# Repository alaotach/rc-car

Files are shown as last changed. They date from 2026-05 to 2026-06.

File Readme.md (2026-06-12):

# Quixie - RC Delivery Car

Quixie is a small autonomous RC delivery car. The custom PCB handles motor control and sensor expansion; the firmware manages navigation, telemetry, and the locking cargo bay.

> Built by **AlAoTach** for [Fallout](https://fallout.hackclub.com/)

Blue and Pink Modern Film Poster

---

## Why I Built This

I wanted to steal chips from my nephew.

---

## Key Features

- **Servo locked cargo bay** - lid opens and closes automatically via servo motor
- **Live camera feed** - ESP32-CAM streamed to the web dashboard
- **GPS navigation** - Neo-8M for real-time position tracking
- **Obstacle avoidance** - 3× ultrasonic sensors
- **OLED display** - SSD1306 1.3" on-device status screen
---

## Tech Specs

| Component | Part |
|---|---|
| MCU | ESP32 Mini (ESP32-S3) |
| Motors | Dual DC Geared, 12V |
| Driver | BTN7960B (43A) |
| GPS | Neo-6M |
| IMU | BMI270 |
| Sensors | Ultrasonic ×3 |
| Camera | ESP32-CAM |
| Display | SSD1306 OLED (1.11") |
| Battery | 3S Li-ion (11.1V) |
| Comms | WiFi — Web + WebSocket |

---

## System Overview

image-Photoroom

---

## What's in This Repo

```
quixie/
├── pcb/                          # KiCad project
│   ├── rc-car.kicad_pcb          # PCB layout
│   ├── rc-car.kicad_sch          # Schematic
│   ├── rc-car.kicad_pro          # Project file
│   ├── rc-car-BOM.csv            # Bill of materials
│   └── fabrication/              # Gerbers + drill files
├── firmware/
│   └── rc-car/
│       ├── include/              # Header files + Config.h
│       └── src/                  # Source files
├── fabrication/
│   └── 3d/
│       ├── rc-car-case.f3d       # Fusion 360 CAD source
│       ├── rc-car-case.stl       # 3D printable case
│       └── pcb-model.stl         # 3D PCB model
└── docs/assets/                  # Images and media
```

---

## PCB

Front and back of the custom PCB:

Screenshot 2026-06-10 111952-Photoroom

Screenshot 2026-06-10 112009-Photoroom

---

## 3D Case

The case is 3D printable in PLA.

rc-car_2026-Jun-09_08-27-36PM-000_CustomizedView2119663068
rc-car_2026-Jun-09_08-28-37PM-000_CustomizedView30783760963
450aec4a-f353-46d9-9899-f3d45b1544f4

**Open cargo bay**

open-lid

---

## Schematic

### Main schema
schema-quixie-1

### Motor schema
schema-quixie-2

### Ultrasonic and TOF
schema-quixie-3

### Servo lock
schema-quixie-4

### Voltage divider
schema-quixie-5

### Battery and charging
schema-quixie-6

---

## Build Guide

### Step 1 - Export Gerbers

Open `pcb/rc-car.kicad_pcb` in KiCad. Generate Gerbers and drill files into `pcb/fabrication/`. Zip all outputs.

### Step 2 - Order the PCB

Upload your Gerber zip to [JLCPCB](https://jlcpcb.com) or your preferred fab.

### Step 3 - Solder & Populate

Solder the required components ( hope you have gotten SMD from jlcpcb )

### Step 4 - Flash Firmware

```bash
cd firmware/rc-car
pio run --target upload
```

Requires [PlatformIO](https://platformio.org/). Main config is in `firmware/rc-car/include/Config.h`.

### Step 5 - 3D Print the Case

- Material: PLA (PETG also works)
- File: `fabrication/3d/rc-car-case.stl`
- No supports needed for most orientations

### Step 6 - Final Assembly

Mount the PCB in the case, wire motors and power, connect sensors. The servo for the lid attaches at the rear hinge point.

---

## Modifying the Firmware

All config parameters live in:

```
firmware/rc-car/include/Config.h
```

Features are split into modules under `firmware/rc-car/src/`.

---

## License

Open source. Do what you want, just don't use it to steal chips from *my* nephew *cough cough*.

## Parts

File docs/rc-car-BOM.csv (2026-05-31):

Reference | Qty | Value | Footprint | Price | Total Price | URL
C1,C4,C10,C12,C13,C20,C27,C34,C39,C44 | 10 | 100nF | Capacitor_SMD:C_0603_1608Metric | 0.07 | 0.7
C2,C3,C9,C11,C19,C23,C24,C26,C33,C38,C43 | 11 | 10uF | Capacitor_SMD:C_0603_1608Metric | 0.07 | 0.77
C5,C6,C7 | 3 | 1uF | Capacitor_SMD:C_0603_1608Metric | 0.07 | 0.21
C8 | 1 | 22pF | Capacitor_SMD:C_0603_1608Metric | 0.07 | 0.07
C14,C15 | 2 | 220uF | Capacitor_SMD:C_0603_1608Metric | 0.07 | 0.14
C25,C32,C37,C42 | 4 | 470uF | Capacitor_SMD:C_0603_1608Metric | 0.07 | 0.28
D1,D2 | 2 | LED | LED_SMD:LED_0201_0603Metric | 0.07 | 0.14
J1 | 1 | UART | Connector_PinHeader_2.54mm:PinHeader_1x03_P2.54mm_Vertical | 3.1 | 3.1 | https://www.electropi.in/usb-to-serial-adapter-module-usb-to-ttl-rs232-arduino-cable-with-cts-rts
J2,J4,J5 | 3 | Ultrasonic | Connector_PinHeader_2.54mm:PinHeader_1x04_P2.54mm_Vertical | 0.72 | 2.16 | https://robu.in/product/hc-sr04-ultrasonic-range-finder/
J3 | 1 | OLED | Connector_PinHeader_2.54mm:PinHeader_1x04_P2.54mm_Vertical | 4.05 | 4.05 | https://robu.in/product/1-3-oled-display-v2/
J6,J7 | 2 | Servo | Connector_PinHeader_2.54mm:PinHeader_1x03_P2.54mm_Vertical | 2.4 | 4.8 | https://www.amazon.in/DHRUVPRO-Micro-Servo-Motor-Helicopter/dp/B09ZT8X5SM
J8 | 1 | BMS | Connector_PinHeader_2.54mm:PinHeader_1x06_P2.54mm_Vertical | 3.7 | 3.7 | https://www.amazon.in/LAND-INDIA-40A-BMS-Over-Discharge/dp/B0D3SMXRV9
J9,J14, J10,J15 | 4 | motor | Connector_PinHeader_2.54mm:PinHeader_1x02_P2.54mm_Vertical | 2.68 | 10.72 | https://robu.in/product/200rpm-12v-low-noise-dc-motor-with-metal-gears-grade-a/
 |  |  |  |  | 0
J11 | 1 | Battery | Connector_JST:JST_XH_B4B-XH-AM_1x04_P2.50mm_Vertical | 12.9 | 12.9 | https://www.electropi.in/11.1v-2200mah-lipo-battery-india
J12 | 1 | XT30PW-M | XT30PW-M:AMASS_XT30PW-M | 0.5 | 0.5 | https://robu.in/product/amass-xt30pw30-female-connector-xt30pw-f30-g-y/
J13 | 1 | USB_C_Receptacle_USB2.0_14P | Connector_USB:USB_C_Receptacle_HRO_TYPE-C-31-M-12 |  | 1
L1 | 1 | 10uH | Inductor_SMD:L_0201_0603Metric | 0.07 | 0.07
Q1,Q2 | 2 | Q_NMOS_GDS | Package_TO_SOT_SMD:TO-263-2 | 0.5 | 1
R1,R4,R6 | 3 | 1kOhm | Resistor_SMD:R_0603_1608Metric_Pad0.98x0.95mm_HandSolder | 0.07 | 0.21
R2,R3,R5 | 3 | 2kOhm | Resistor_SMD:R_0603_1608Metric_Pad0.98x0.95mm_HandSolder | 0.07 | 0.21
R7,R9 | 2 | 5.1kOhm | Resistor_SMD:R_0603_1608Metric_Pad0.98x0.95mm_HandSolder | 0.07 | 0.14
R10,R11,R12,R13,R14,R15 | 6 | 10kOhm | Resistor_SMD:R_0603_1608Metric | 0.07 | 0.42
R16 | 1 | 5.23kOhm | Resistor_SMD:R_0603_1608Metric | 0.07 | 0.07
R17 | 1 | 30.1kOhm | Resistor_SMD:R_0603_1608Metric | 0.07 | 0.07
R18 | 1 | 20mOhm | Resistor_SMD:R_0603_1608Metric | 0.07 | 0.07
R19,R21 | 2 | 499kOhm | Resistor_SMD:R_0603_1608Metric | 0.07 | 0.14
R20 | 1 | 100kOhm | Resistor_SMD:R_0603_1608Metric | 0.07 | 0.07
R22 | 1 | 36kOhm | Resistor_SMD:R_0603_1608Metric | 0.07 | 0.07
TH1 | 1 | Thermistor | Resistor_SMD:R_0805_2012Metric | 0.07 | 0.07
U1 | 1 | ESP32-S3-MINI-1 | RF_Module:ESP32-S2-MINI-1 | 18.7 | 18.7 | https://www.amazon.in/dp/B0G8ZWDDM6
U2 | 1 | AP2112K-3.3 | Package_TO_SOT_SMD:SOT-23-5 | 0.25 | 0.25 | https://robu.in/product/ap2112k-1-8trg1-diodes-incorporated-65db1khz-600ma-fixed-1-8v-positive-6v-sot-25-voltage-regulators-linear-low-drop-out-ldo-regulators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
U3 | 1 | NEO-M8M | RF_GPS:ublox_NEO | 10.2 | 10.2 | https://robu.in/product/apm2-5-ublox-neo-m8n-gps-module-gygpsv1-8m-3-5v-gygpsv5-neo-pixhawk-apm-ceramic-active-antenna/
U4 | 1 | IP2721 | Package_SO:TSSOP-16_4.4x5mm_P0.65mm | 1 | 1 | https://www.jakelectronics.com/productdetail/injoinic-ip2721-21164566
U5 | 1 | BQ24650 | Package_DFN_QFN:Texas_RVA_VQFN-16-1EP_3.5x3.5mm_P0.5mm_EP2.14x2.14mm_ThermalVias | 6 | 6 | https://www.lioncircuits.com/parts/BQ24650RVAR
U6 | 1 | LM2596S-5 | Package_TO_SOT_SMD:TO-263-5_TabPin3 | 0.7 | 0.7 | https://robu.in/product/lm2596s-5-0-xblw-step-down-type-fixed-5v-to-263-5l-dc-dc-converters-rohs/
U7 | 1 | TMF8828 | Sensor_Distance:AMS_OLGA12 | 1.32 | 1.32 | https://robu.in/product/vl53l0x-tof-based-lidar-laser-distance-sensor/
U8 | 1 | BMI270 | BMI270:XDCR_BMI270 | 3.4 | 3.4 | https://www.utmel.com/productdetail/boschsensortec-bmi270-6195042
U9,U10,U11,U12 | 4 | BTN7960B_LA | BTN7960B:IC_BTN7960B | 1.55 | 6.2 | https://www.ktron.in/product/bts7960-motor-driver-ic-43a-h-bridge-high/
 |  |  |  |  | 95.62

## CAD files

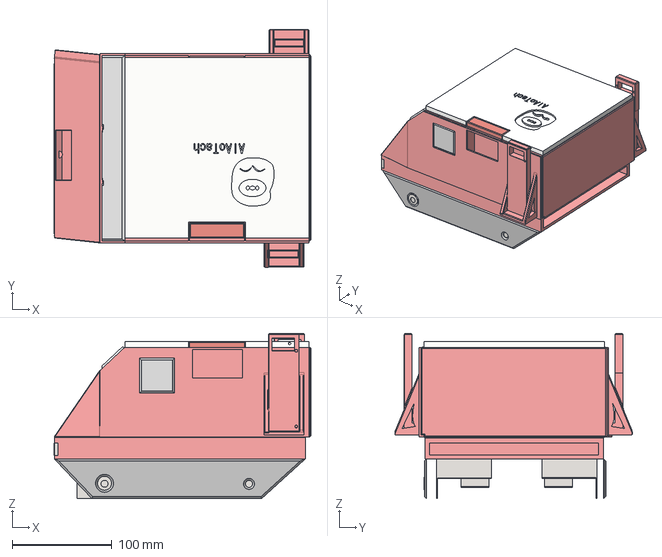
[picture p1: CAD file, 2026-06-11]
fabrication/3d/rc-car.step
258.1 x 238.7 x 166.0 mm

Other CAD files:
fabrication/3d/rc-car-case.stl
fabrication/3d/pcb-model.stl
fabrication/3d/rc-car-case.f3d

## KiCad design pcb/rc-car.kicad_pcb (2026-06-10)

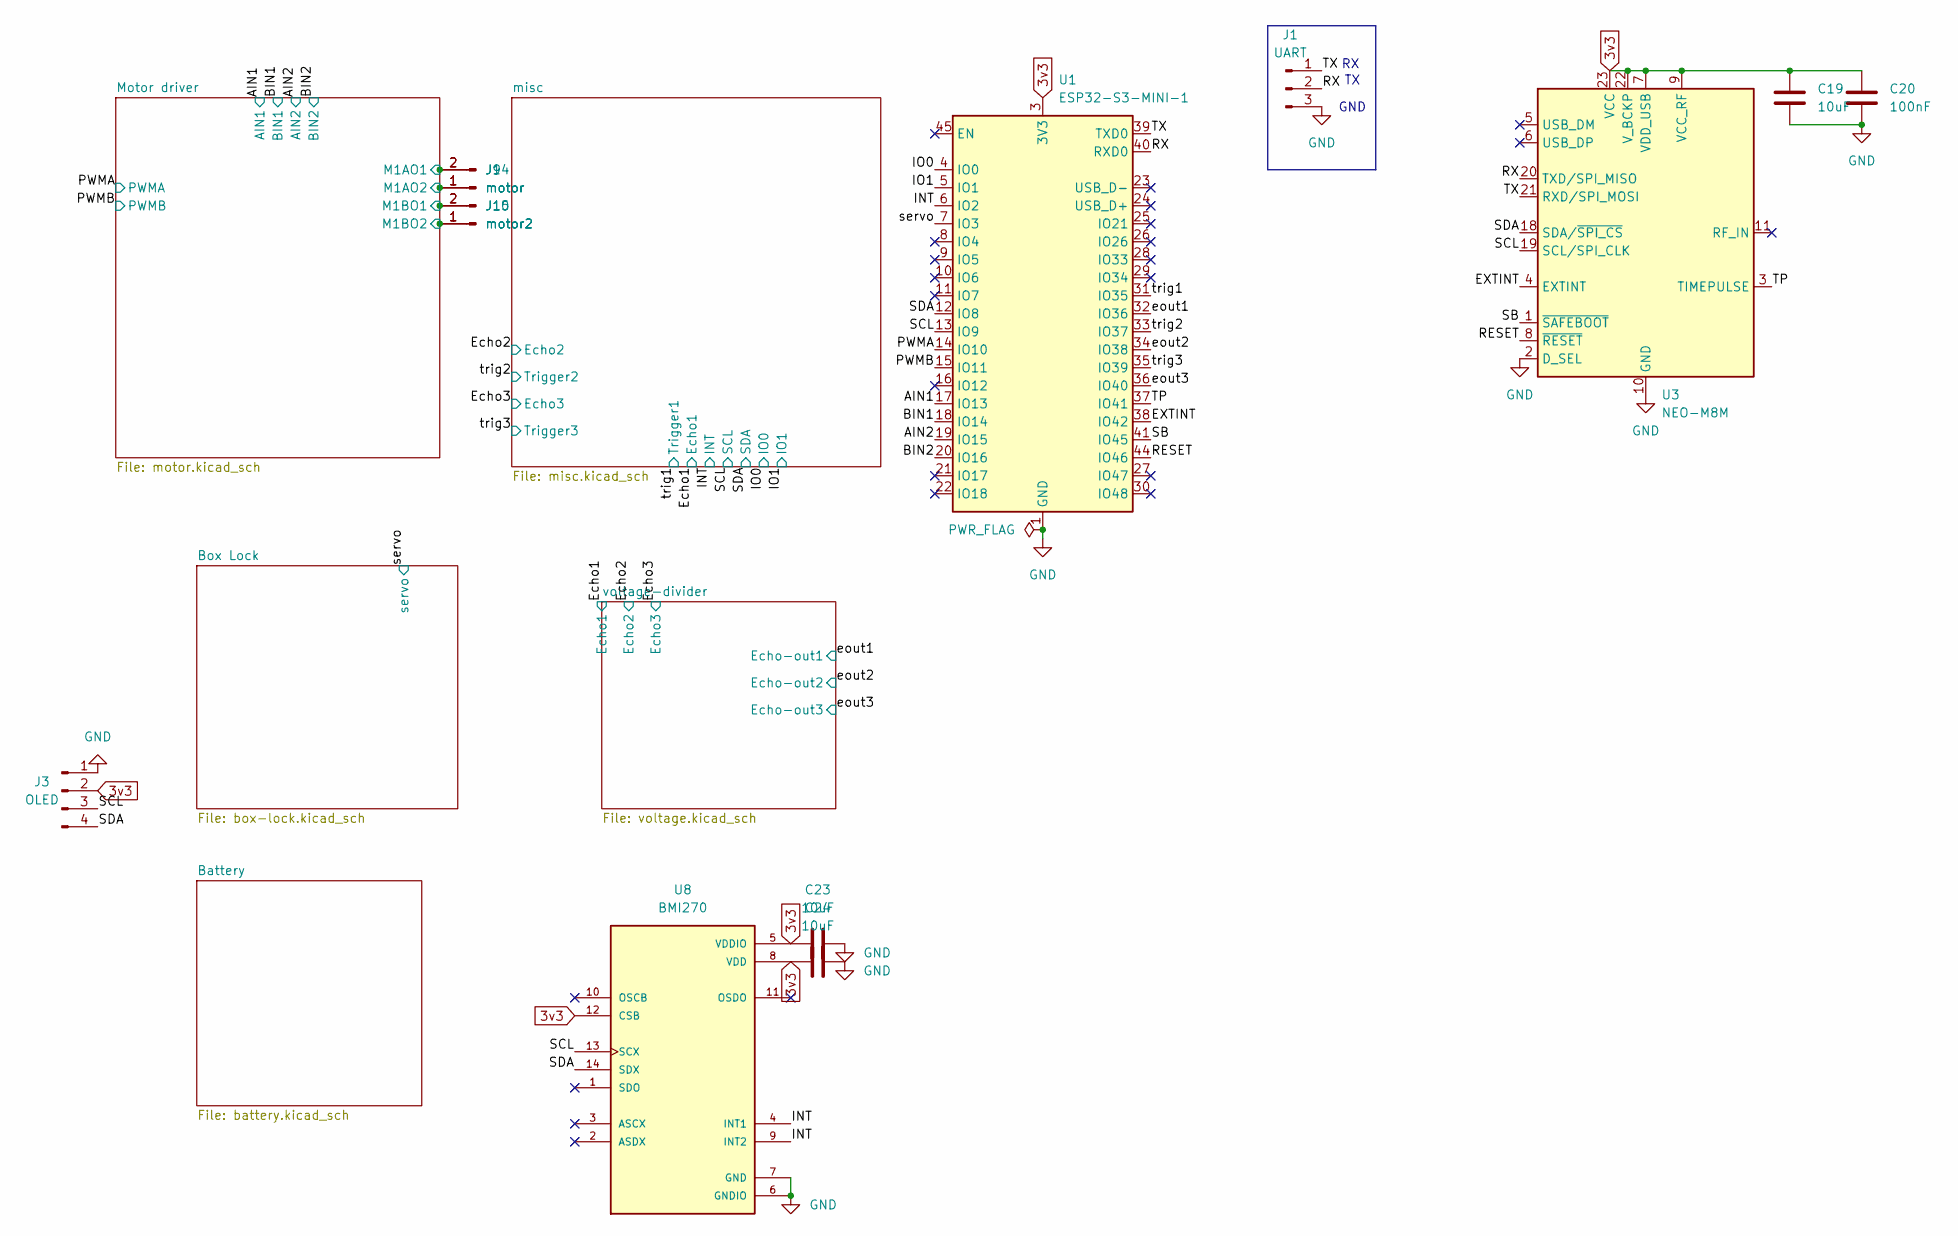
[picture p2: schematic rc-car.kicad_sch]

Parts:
C19, C23, C24: 10uF; C_0603_1608Metric
C20: 100nF; C_0603_1608Metric
J1: UART; PinHeader_1x03_P2.54mm_Vertical
J3: OLED; PinHeader_1x04_P2.54mm_Vertical
J9, J14: motor; PinHeader_1x02_P2.54mm_Vertical
J10, J15: motor2; PinHeader_1x02_P2.54mm_Vertical
U1: ESP32-S3-MINI-1; ESP32-S2-MINI-1
U3: NEO-M8M; ublox_NEO
U8: BMI270; XDCR_BMI270

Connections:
3v3: C19.1, C20.1, C23.1, C24.1, J3.2, U1.3 (3V3), U3.7 (VDD_USB), U3.9 (VCC_RF), U3.22 (V_BCKP), U3.23 (VCC), U8.5 (VDDIO), U8.8 (VDD), U8.12 (CSB); also elsewhere on the board
/AIN1: U1.17 (IO13); also elsewhere on the board
/AIN2: U1.19 (IO15); also elsewhere on the board
/BIN1: U1.18 (IO14); also elsewhere on the board
/BIN2: U1.20 (IO16); also elsewhere on the board
/EXTINT: U1.38 (IO42), U3.4 (EXTINT)
/INT: U1.6 (IO2), U8.4 (INT1), U8.9 (INT2); also elsewhere on the board
/IO0: U1.4 (IO0); also elsewhere on the board
/IO1: U1.5 (IO1); also elsewhere on the board
/Motor driver/M1AO1: J9.2, J14.2; also elsewhere on the board
/Motor driver/M1AO2: J9.1, J14.1; also elsewhere on the board
/Motor driver/M1BO1: J10.2, J15.2; also elsewhere on the board
/Motor driver/M1BO2: J10.1, J15.1; also elsewhere on the board
/PWMA: U1.14 (IO10); also elsewhere on the board
/PWMB: U1.15 (IO11); also elsewhere on the board
/RESET: U1.44 (IO46), U3.8 (~RESET)
/RX: J1.2, U1.40 (RXD0), U3.20 (TXD/SPI_MISO)
/SB: U1.41 (IO45), U3.1 (~SAFEBOOT)
/SCL: J3.3, U1.13 (IO9), U3.19 (SCL/SPI_CLK), U8.13 (SCX); also elsewhere on the board
/SDA: J3.4, U1.12 (IO8), U3.18 (SDA/~SPI_CS), U8.14 (SDX); also elsewhere on the board
/TP: U1.37 (IO41), U3.3 (TIMEPULSE)
/TX: J1.1, U1.39 (TXD0), U3.21 (RXD/SPI_MOSI)
/eout1: U1.32 (IO36); also elsewhere on the board
/eout2: U1.34 (IO38); also elsewhere on the board
/eout3: U1.36 (IO40); also elsewhere on the board
/servo: U1.7 (IO3); also elsewhere on the board
/trig1: U1.31 (IO35); also elsewhere on the board
/trig2: U1.33 (IO37); also elsewhere on the board
/trig3: U1.35 (IO39); also elsewhere on the board
GND: C19.2, C20.2, C23.2, C24.2, J1.3, J3.1, U1.1 (GND), U1.2 (GND), U1.42 (GND), U1.43 (GND), U1.46 (GND), U1.47 (GND), U1.48 (GND), U1.49 (GND), U1.50 (GND), U1.51 (GND), U1.52 (GND), U1.53 (GND), U1.54 (GND), U1.55 (GND), U1.56 (GND), U1.57 (GND), U1.58 (GND), U1.59 (GND), U1.60 (GND), U1.61 (GND), U1.62 (GND), U1.63 (GND), U1.64 (GND), U1.65 (GND), U3.2 (D_SEL), U3.10 (GND), U3.12 (GND), U3.13 (GND), U3.24 (GND), U8.6 (GNDIO), U8.7 (GND); also elsewhere on the board

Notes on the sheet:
GND

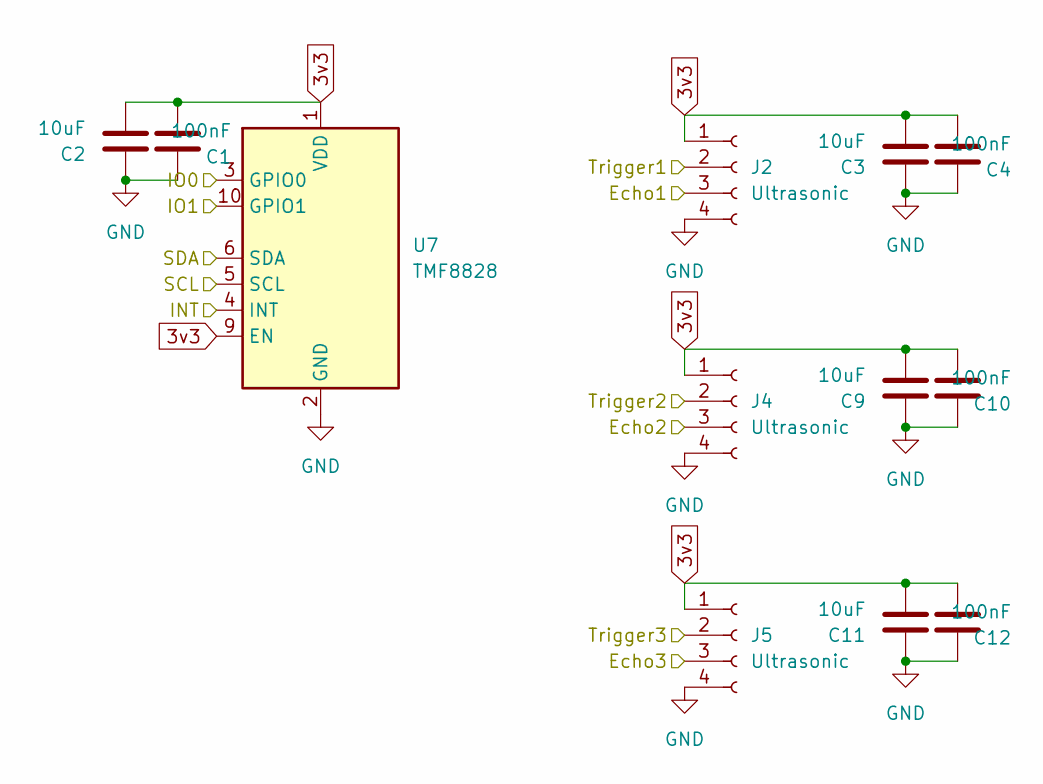
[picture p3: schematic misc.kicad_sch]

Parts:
C1, C4, C10, C12: 100nF; C_0603_1608Metric
C2, C3, C9, C11: 10uF; C_0603_1608Metric
J2, J4, J5: Ultrasonic; PinHeader_1x04_P2.54mm_Vertical
U7: TMF8828; AMS_OLGA12

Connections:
3v3: C1.1, C2.2, C3.2, C4.1, C9.2, C10.1, C11.2, C12.1, J2.1, J4.1, J5.1, U7.1 (VDD), U7.7 (VDD), U7.9 (EN), U7.12 (VDD); also elsewhere on the board
/Echo1: J2.3; also elsewhere on the board
/Echo2: J4.3; also elsewhere on the board
/Echo3: J5.3; also elsewhere on the board
/INT: U7.4 (INT); also elsewhere on the board
/IO0: U7.3 (GPIO0); also elsewhere on the board
/IO1: U7.10 (GPIO1); also elsewhere on the board
/SCL: U7.5 (SCL); also elsewhere on the board
/SDA: U7.6 (SDA); also elsewhere on the board
/trig1: J2.2; also elsewhere on the board
/trig2: J4.2; also elsewhere on the board
/trig3: J5.2; also elsewhere on the board
GND: C1.2, C2.1, C3.1, C4.2, C9.1, C10.2, C11.1, C12.2, J2.4, J4.4, J5.4, U7.2 (GND), U7.8 (GND), U7.11 (GND); also elsewhere on the board

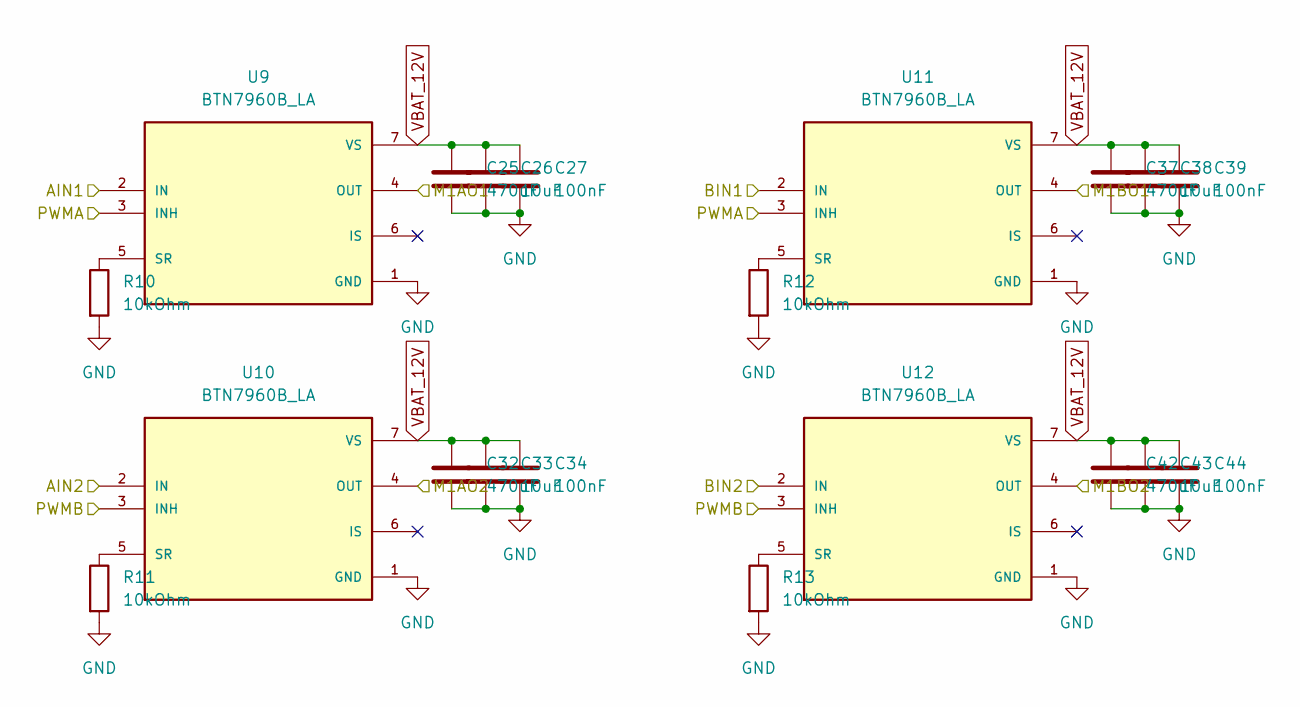
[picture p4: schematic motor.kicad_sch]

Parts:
C25, C32, C37, C42: 470uF; C_0603_1608Metric
C26, C33, C38, C43: 10uF; C_0603_1608Metric
C27, C34, C39, C44: 100nF; C_0603_1608Metric
R10, R11, R12, R13: 10kOhm; R_0603_1608Metric
U9, U10, U11, U12: BTN7960B_LA; IC_BTN7960B; PARTREV 1.0

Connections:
/AIN1: U9.2 (IN); also elsewhere on the board
/AIN2: U10.2 (IN); also elsewhere on the board
/BIN1: U11.2 (IN); also elsewhere on the board
/BIN2: U12.2 (IN); also elsewhere on the board
/Motor driver/M1AO1: U9.4 (OUT), U9.8 (OUT); also elsewhere on the board
/Motor driver/M1AO2: U10.4 (OUT), U10.8 (OUT); also elsewhere on the board
/Motor driver/M1BO1: U11.4 (OUT), U11.8 (OUT); also elsewhere on the board
/Motor driver/M1BO2: U12.4 (OUT), U12.8 (OUT); also elsewhere on the board
/PWMA: U9.3 (INH), U11.3 (INH); also elsewhere on the board
/PWMB: U10.3 (INH), U12.3 (INH); also elsewhere on the board
GND: C25.2, C26.2, C27.2, C32.2, C33.2, C34.2, C37.2, C38.2, C39.2, C42.2, C43.2, C44.2, R10.2, R11.2, R12.2, R13.2, U9.1 (GND), U10.1 (GND), U11.1 (GND), U12.1 (GND); also elsewhere on the board
unnamed: R10.1, U9.5 (SR)
unnamed: R11.1, U10.5 (SR)
unnamed: R12.1, U11.5 (SR)
unnamed: R13.1, U12.5 (SR)
VBAT_12V: C25.1, C26.1, C27.1, C32.1, C33.1, C34.1, C37.1, C38.1, C39.1, C42.1, C43.1, C44.1, U9.7 (VS), U10.7 (VS), U11.7 (VS), U12.7 (VS); also elsewhere on the board

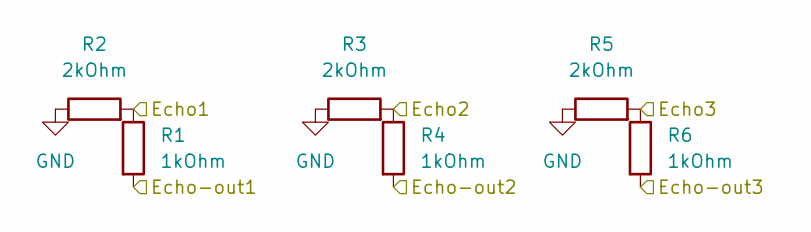
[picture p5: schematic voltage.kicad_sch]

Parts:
R1, R4, R6: 1kOhm; R_0603_1608Metric_Pad0.98x0.95mm_HandSolder
R2, R3, R5: 2kOhm; R_0603_1608Metric_Pad0.98x0.95mm_HandSolder

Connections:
/Echo1: R1.1, R2.2; also elsewhere on the board
/Echo2: R3.2, R4.1; also elsewhere on the board
/Echo3: R5.2, R6.1; also elsewhere on the board
/eout1: R1.2; also elsewhere on the board
/eout2: R4.2; also elsewhere on the board
/eout3: R6.2; also elsewhere on the board
GND: R2.1, R3.1, R5.1; also elsewhere on the board

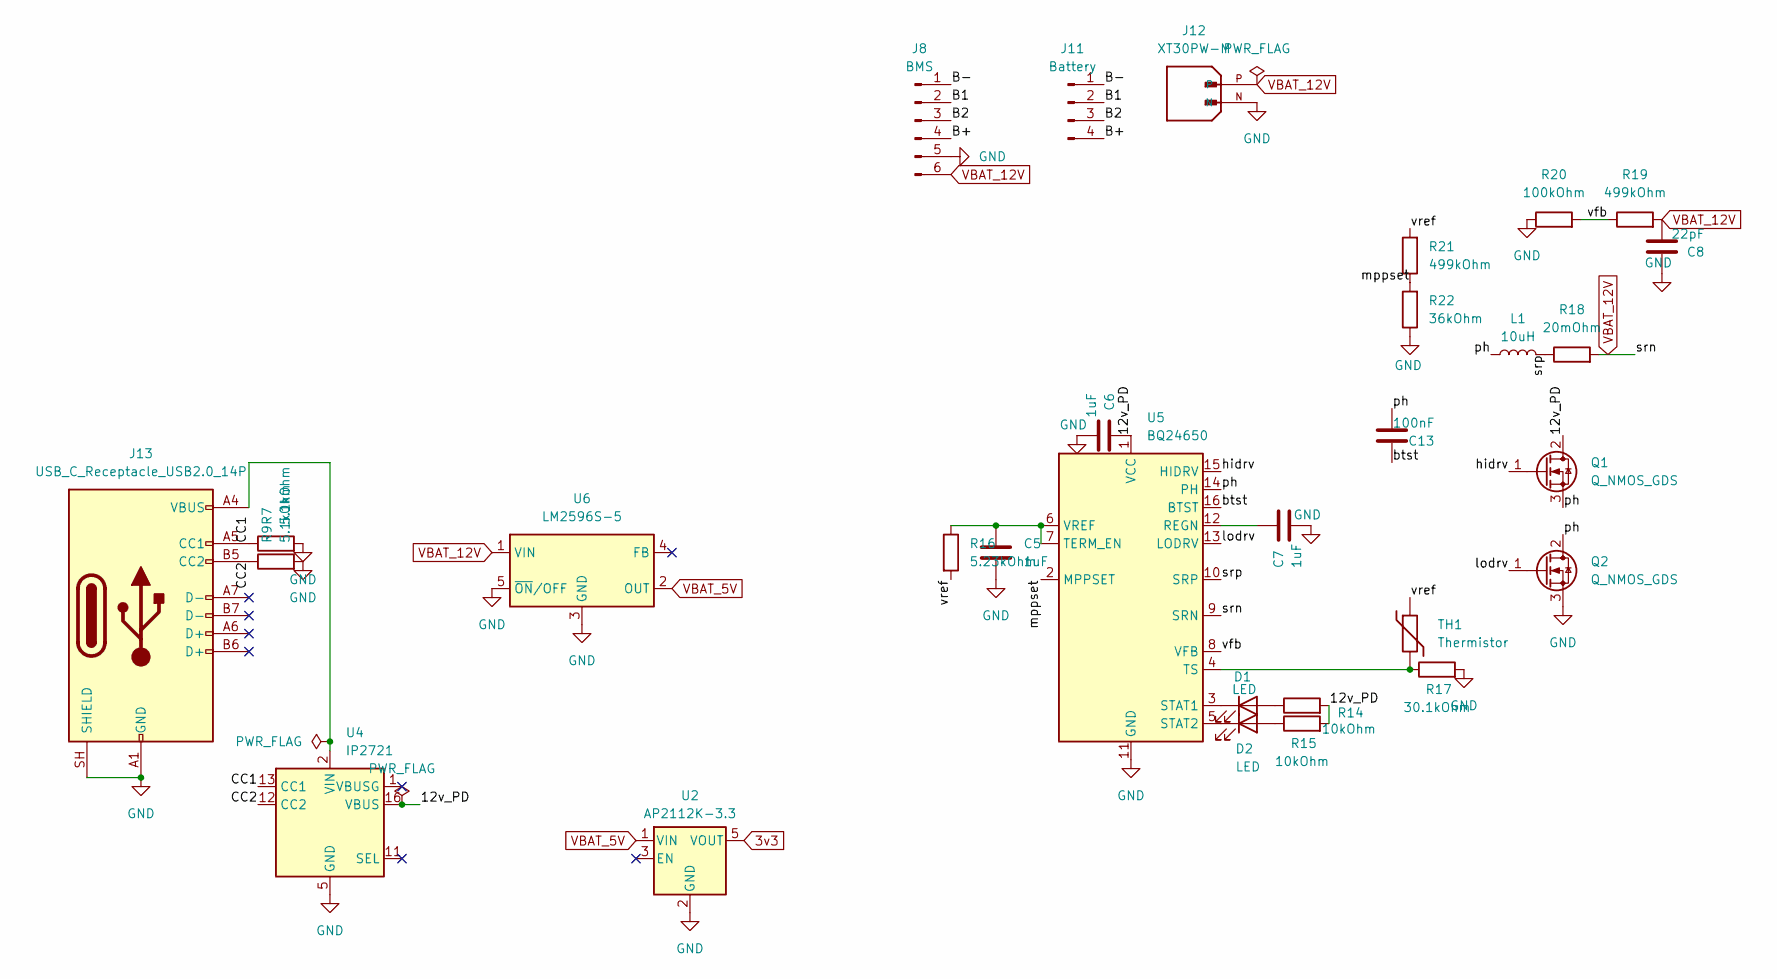
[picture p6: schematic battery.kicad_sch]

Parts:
C5, C6, C7: 1uF; C_0603_1608Metric
C8: 22pF; C_0603_1608Metric
C13: 100nF; C_0603_1608Metric
D1, D2: LED; LED_0201_0603Metric
J8: BMS; PinHeader_1x06_P2.54mm_Vertical
J11: Battery; JST_XH_B4B-XH-AM_1x04_P2.50mm_Vertical
J12: XT30PW-M; AMASS_XT30PW-M; PARTREV 1.2
J13: USB_C_Receptacle_USB2.0_14P; USB_C_Receptacle_HRO_TYPE-C-31-M-12
L1: 10uH; L_0201_0603Metric
Q1, Q2: Q_NMOS_GDS; TO-263-2
R7, R9: 5.1kOhm; R_0603_1608Metric_Pad0.98x0.95mm_HandSolder
R14, R15: 10kOhm; R_0603_1608Metric
R16: 5.23kOhm; R_0603_1608Metric
R17: 30.1kOhm; R_0603_1608Metric
R18: 20mOhm; R_0603_1608Metric
R19, R21: 499kOhm; R_0603_1608Metric
R20: 100kOhm; R_0603_1608Metric
R22: 36kOhm; R_0603_1608Metric
TH1: Thermistor; R_0805_2012Metric
U2: AP2112K-3.3; SOT-23-5
U4: IP2721; TSSOP-16_4.4x5mm_P0.65mm
U5: BQ24650; Texas_RVA_VQFN-16-1EP_3.5x3.5mm_P0.5mm_EP2.14x2.14mm_Therma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
U6: LM2596S-5; TO-263-5_TabPin3

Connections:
3v3: U2.5 (VOUT); also elsewhere on the board
/Battery/12v_PD: C6.1, Q1.2 (D), R14.2, R15.2, U4.16 (VBUS), U5.1 (VCC)
/Battery/B1: J8.2, J11.2
/Battery/B2: J8.3, J11.3
/Battery/B+: J8.4, J11.4
/Battery/B-: J8.1, J11.1
/Battery/CC1: J13.A5 (CC1), R7.1, U4.13 (CC1)
/Battery/CC2: J13.B5 (CC2), R9.1, U4.12 (CC2)
/Battery/btst: C13.1, U5.16 (BTST)
/Battery/hidrv: Q1.1 (G), U5.15 (HIDRV)
/Battery/lodrv: Q2.1 (G), U5.13 (LODRV)
/Battery/mppset: R21.1, R22.2, U5.2 (MPPSET)
/Battery/ph: C13.2, L1.1, Q1.3 (S), Q2.2 (D), U5.14 (PH)
/Battery/srp: L1.2, R18.1, U5.10 (SRP)
/Battery/vfb: R19.1, R20.2, U5.8 (VFB)
/Battery/vref: R16.2, R21.2, TH1.1
GND: C5.2, C6.2, C7.2, C8.1, J8.5, J12.N, J13.A1 (GND), J13.A12 (GND), J13.B1 (GND), J13.B12 (GND), J13.SH (SHIELD), Q2.3 (S), R7.2, R9.2, R17.2, R20.1, R22.1, U2.2 (GND), U4.5 (GND), U5.11 (GND), U5.17 (GND), U6.3 (GND), U6.5 (~ON/OFF); also elsewhere on the board
unnamed: D1.2 (A), R14.1
unnamed: D1.1 (K), U5.3 (STAT1)
unnamed: D2.2 (A), R15.1
unnamed: D2.1 (K), U5.5 (STAT2)
unnamed: J13.A4 (VBUS), J13.A9 (VBUS), J13.B4 (VBUS), J13.B9 (VBUS), U4.2 (VIN)
unnamed: C7.1, U5.12 (REGN)
unnamed: C5.1, R16.1, U5.6 (VREF), U5.7 (TERM_EN)
unnamed: R17.1, TH1.2, U5.4 (TS)
VBAT_5V: U2.1 (VIN), U6.2 (OUT); also elsewhere on the board
VBAT_12V: C8.2, J8.6, J12.P, R18.2, R19.2, U5.9 (SRN), U6.1 (VIN); also elsewhere on the board

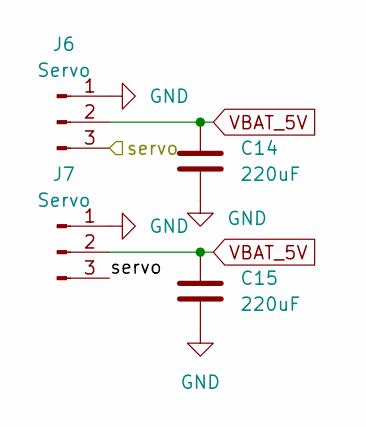
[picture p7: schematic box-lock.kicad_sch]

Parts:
C14, C15: 220uF; C_0603_1608Metric
J6, J7: Servo; PinHeader_1x03_P2.54mm_Vertical

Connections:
/servo: J6.3, J7.3; also elsewhere on the board
GND: C14.2, C15.1, J6.1, J7.1; also elsewhere on the board
VBAT_5V: C14.1, C15.2, J6.2, J7.2; also elsewhere on the board

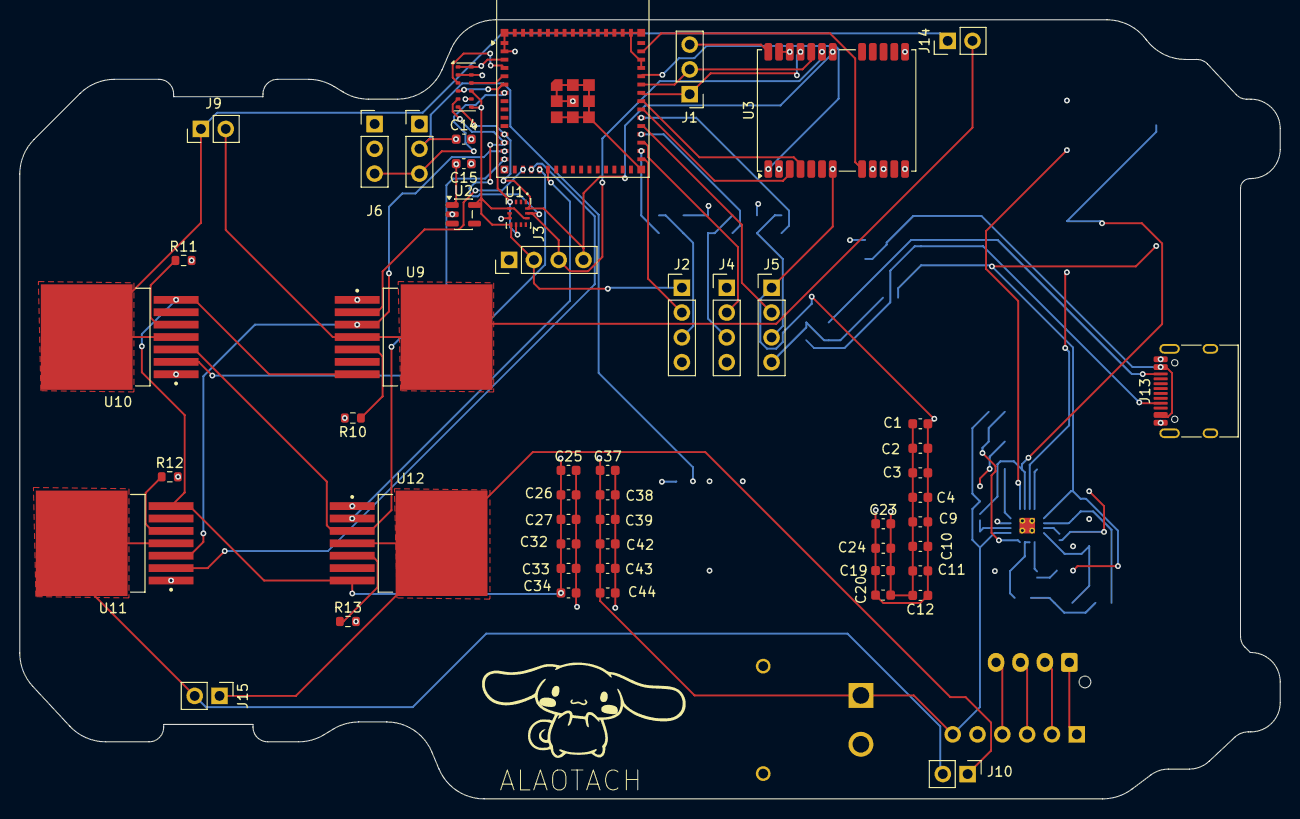
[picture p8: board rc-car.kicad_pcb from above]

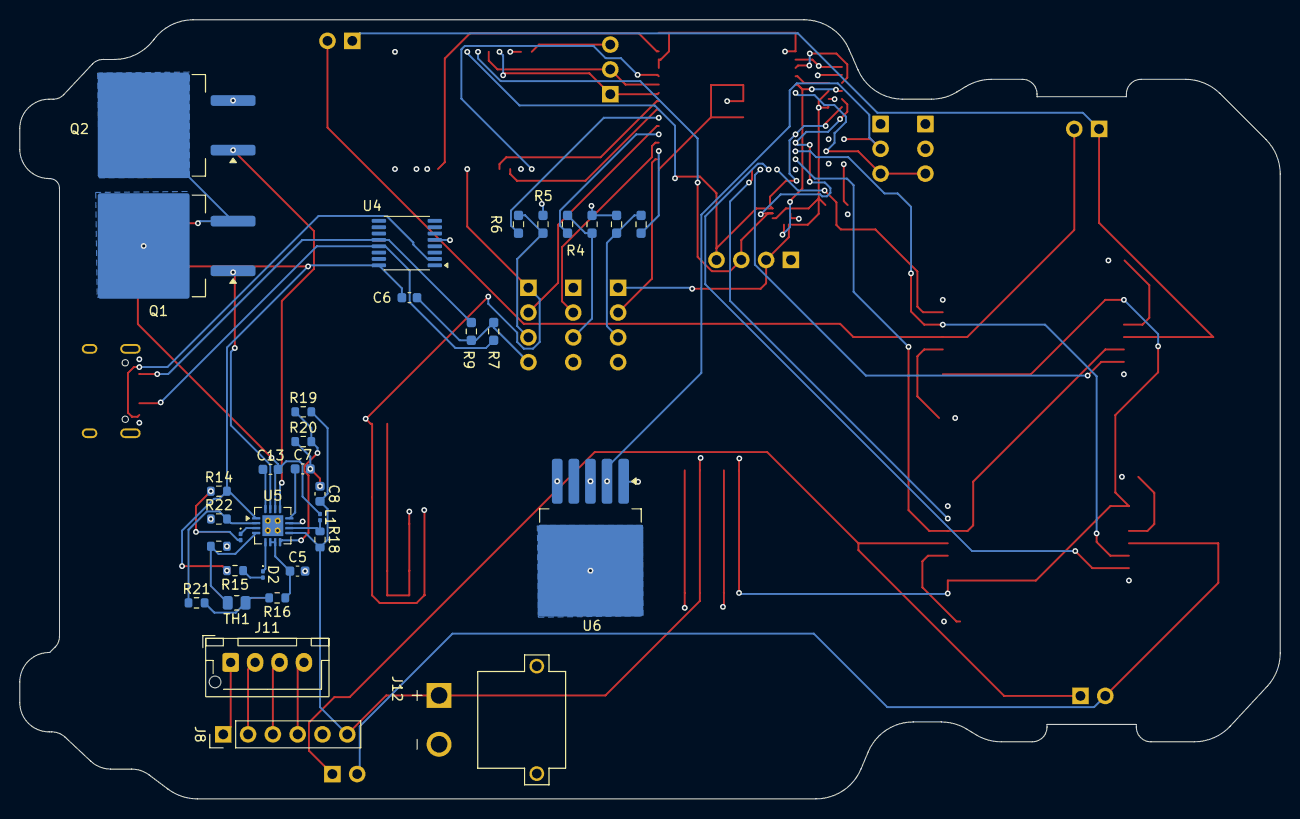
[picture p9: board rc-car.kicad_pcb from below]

Board: 4 copper layers, 129.0 x 79.8 mm, 85 parts (34 on the bottom side), 62 nets.

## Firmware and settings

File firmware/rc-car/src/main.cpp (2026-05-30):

#include <Arduino.h>
#include <WiFi.h>
#include <ESPAsyncWebServer.h>
#include <AsyncTCP.h>
#include <Wire.h>
#include <esp_camera.h>
#include "Config.h"
#include "Web.h"
#include "Nav.h"
#include "Gps.h"
#include "IMU.h"
#include "Motor.h"
#include "Camera.h"

void setup() {
    Serial.begin(115200);
    Wire.begin();
    GPSM::init();
    IMUM::init();
    MotorM::init();
    CameraM::init();
    WebM::init();
    NavM::init();
    xTaskCreatePinnedToCore(navTask, "nav", 4096, nullptr, 1, nullptr, 1);
    xTaskCreatePinnedToCore(gpsTask, "gps", 4096, nullptr, 1, nullptr, 1);
    xTaskCreatePinnedToCore(imuTask, "imu", 4096, nullptr, 1, nullptr, 1);
    Serial.println("Setup done");
}

void navTask(void*){
  while(true){
    NavM::update();
  }
}

void gpsTask(void*){
  while(true){
    GPSM::update();
  }
}


void imuTask(void*){
  while(true){
    IMUM::update();
  }
}
void loop() {
  delay(2000);
}

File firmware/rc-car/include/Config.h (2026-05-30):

#ifndef CONFIG_H
#define CONFIG_H

#define WIFI_SSID "Samsung a35"
#define WIFI_PASS "samsung1"
#define GPS_RX 19
#define GPS_TX 20
#define MOTORPWMA 10
#define MOTORPWMB 11
#define MOTORAIN1 13
#define MOTORAIN2 15
#define MOTORBIN1 14
#define MOTORBIN2 16
#define TRIG1 35
#define TRIG2 37
#define TRIG3 39
#define ECHO1 36
#define ECHO2 38
#define ECHO3 40
#define SERVO 3

#endif

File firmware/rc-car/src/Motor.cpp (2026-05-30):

#include <Arduino.h>
#include "Motor.h"
#include "Config.h"

static int speed = 0;

void MotorM::init() {
  pinMode(MOTORAIN1, OUTPUT);
  pinMode(MOTORAIN2, OUTPUT);
  pinMode(MOTORBIN1, OUTPUT);
  pinMode(MOTORBIN2, OUTPUT);
  pinMode(MOTORPWMA, OUTPUT);
  pinMode(MOTORPWMB, OUTPUT);
  ledcAttachPin(MOTORPWMA, 0);
  ledcAttachPin(MOTORPWMB, 1);
  MotorM::stop();
}

void MotorM::stop() {
  digitalWrite(MOTORAIN1, LOW);
  digitalWrite(MOTORAIN2, LOW);
  digitalWrite(MOTORBIN1, LOW);
  digitalWrite(MOTORBIN2, LOW);
  ledcWrite(0, 0);
  ledcWrite(1, 0);
}

void MotorM::forward(int speed) {
  digitalWrite(MOTORAIN1, HIGH);
  digitalWrite(MOTORAIN2, LOW);
  digitalWrite(MOTORBIN1, HIGH);
  digitalWrite(MOTORBIN2, LOW);
  ledcWrite(0, speed);
  ledcWrite(1, speed);
}

void MotorM::backward(int speed) {
  digitalWrite(MOTORAIN1, LOW);
  digitalWrite(MOTORAIN2, HIGH);
  digitalWrite(MOTORBIN1, LOW);
  digitalWrite(MOTORBIN2, HIGH);
  ledcWrite(0, speed);
  ledcWrite(1, speed);
}

void MotorM::left(int speed) {
  digitalWrite(MOTORAIN1, LOW);
  digitalWrite(MOTORAIN2, HIGH);
  digitalWrite(MOTORBIN1, HIGH);
  digitalWrite(MOTORBIN2, LOW);
  ledcWrite(0, speed);
  ledcWrite(1, speed);
}

void MotorM::right(int speed) {
  digitalWrite(MOTORAIN1, HIGH);
  digitalWrite(MOTORAIN2, LOW);
  digitalWrite(MOTORBIN1, LOW);
  digitalWrite(MOTORBIN2, HIGH);
  ledcWrite(0, speed);
  ledcWrite(1, speed);
}

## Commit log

2026-05-30 created required header files
    [battery.kicad_sch, box-lock.kicad_sch, misc.kicad_sch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]
2026-05-30 gps, motor and ultrasonic sensor basic done
2026-05-30 basic navigation system, obstacle avoidance, go to waypoint etc
    [IMU.cpp, Nav.cpp]
2026-05-31 files organized and readme
    [battery.kicad_sch, box-lock.kicad_sch, misc.kicad_sch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]
2026-06-10 case update
    [rc-car-B_Cu.gbr, rc-car-B_Mask.gbr, rc-car-B_Paste.gbr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]
